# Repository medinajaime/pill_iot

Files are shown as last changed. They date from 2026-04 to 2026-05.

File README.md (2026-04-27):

# Smart Pill Dispenser (智慧藥盒)

An IoT smart medication management system designed for Taiwan's elderly population. The companion app combines prescription recognition with automatic dispensing to help users manage their medications safely and effectively.

## Features

- **Prescription Scanning** - Scan Taiwan NHI prescription QR codes to automatically import medications
- **Medication Scheduling** - Daily and weekly medication schedule views
- **Adherence Tracking** - Track medication compliance with history and statistics
- **IoT Dispenser Integration** - Connect to smart pill dispenser via Bluetooth/WiFi
- **Caregiver Dashboard** - Allow family members to monitor medication adherence remotely
- **Multi-language Support** - English and Traditional Chinese (繁體中文)
- **Elderly-Friendly UI** - Large fonts, high contrast options, voice prompts

## Screenshots

*Coming soon*

## Getting Started

### Prerequisites

- Flutter SDK 3.16.0 or higher
- Android Studio / VS Code
- Java JDK 17
- Android SDK (API 23+)

### Installation

1. **Clone the repository**
   ```bash
   git clone git@github.com:medinajaime/pill_iot_dispenser.git
   cd pill_iot_dispenser
   ```

2. **Install dependencies**
   ```bash
   flutter pub get
   ```

3. **Generate code** (for freezed/json_serializable)
   ```bash
   dart run build_runner build --delete-conflicting-outputs
   ```

4. **Run the app**
   ```bash
   flutter run
   ```

### Firebase Setup (Required for Production)

1. Create a Firebase project at [console.firebase.google.com](https://console.firebase.google.com)
2. Enable Authentication, Firestore, Cloud Messaging, and Storage
3. Download `google-services.json` and place in `android/app/`
4. Run `flutterfire configure` to generate Firebase options
5. Uncomment Firebase initialization in `lib/main.dart`

## Project Structure

```
lib/
├── main.dart                 # App entry point
├── app.dart                  # MaterialApp configuration
├── core/
│   ├── localization/         # i18n (English & Chinese)
│   ├── router/               # GoRouter navigation
│   ├── theme/                # App theme & styling
│   └── utils/                # Utilities (QR parser, etc.)
├── data/
│   └── models/               # Data models (freezed)
├── presentation/
│   ├── providers/            # Riverpod state management
│   ├── screens/              # App screens
│   └── widgets/              # Reusable widgets
└── services/                 # Business logic & API services
```

## Tech Stack

| Category | Technology |
|---|---|
| Framework | Flutter 3.16+ |
| State Management | Riverpod |
| Navigation | GoRouter |
| Local Storage | Hive, SharedPreferences |
| Backend | Firebase (Auth, Firestore, Messaging, Storage) |
| Bluetooth | flutter_blue_plus |
| QR Scanning | mobile_scanner |
| Notifications | flutter_local_notifications |

## Building

### Debug APK
```bash
flutter build apk --debug
```

### Release APK
```bash
flutter build apk --release
```

### App Bundle (Play Store)
```bash
flutter build appbundle --release
```

Output location: `build/app/outputs/flutter-apk/`

## Configuration

### Environment Variables

Create `android/app/google-services.json` with your Firebase configuration (not committed to git).

### Changing App ID

Update the application ID in `android/app/build.gradle.kts`:
```kotlin
applicationId = "com.yourcompany.smartpilldispenser"
```

## Localization

The app supports:
- **English** (en-US)
- **Traditional Chinese** (zh-TW)

Language can be switched in Settings > Display Settings > Language.

To add translations, edit `lib/core/localization/app_localizations.dart`.

## Development

### Demo Mode

The app includes a demo mode with mock data for testing without a real dispenser. Toggle in Settings > Developer Options > Demo Mode.

### Running Tests
```bash
flutter test
```

### Code Generation
```bash
dart run build_runner watch  # Watch mode
dart run build_runner build --delete-conflicting-outputs  # One-time build
```

## Roadmap

See [TASKS.md](TASKS.md) for detailed integration tasks and remaining work.

### Priority Features
- [ ] Firebase backend integration
- [ ] Push notifications for medication reminders
- [ ] Real Bluetooth device pairing
- [ ] LINE messaging integration
- [ ] Voice prompts (Mandarin/Hokkien)

## Contributing

1. Fork the repository
2. Create a feature branch (`git checkout -b feature/amazing-feature`)
3. Commit your changes (`git commit -m 'Add amazing feature'`)
4. Push to the branch (`git push origin feature/amazing-feature`)
5. Open a Pull Request

## Authors

- **Marcus Canul**
- **Jaime Medina**

## License

This project is proprietary. All rights reserved.

## Acknowledgments

- Designed for Taiwan's National Health Insurance (NHI) prescription system
- Built with accessibility in mind for elderly users
- IoT hardware integration for automated pill dispensing

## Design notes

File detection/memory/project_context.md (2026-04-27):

---
name: Hero Smart Pill Dispenser — Project Context
description: Full context of the pill detection system being built for a Taiwan-focused IoT smart pill dispenser
type: project
---

Smart IoT pill dispenser for Taiwan's elderly population. School project (Jaime Medina + Marcus Canul).

**Core flow:**
1. User scans paper prescription or NHI QR code in Flutter app
2. App OCRs/parses prescription → sends medication list (with NHI codes, color, shape) to Pi over BLE
3. User physically loads pills one medication type at a time (no app guidance required)
4. Pi camera images each pill in optical chamber → identifies which prescription medication it is
5. Routes pill to correct carousel slot
6. Pills dispensed automatically on schedule, or on demand

**Why:** Taiwan becoming super-aged society (20%+ over 65 by 2025). Reduces medication errors and caregiver burden.

**Detection approach:**
- Open identification against ≤10 prescription medications (not global database)
- MobileNetV2 fine-tuned on ePillID public dataset → TFLite INT8 for Pi 4
- Metric learning: embedding-based matching (cosine similarity), no retraining when new pills added
- Auto-registration: first 3-5 pills of each type captured automatically; NHI color/shape used as prior
- Three outcomes: MATCH (auto-route) / UNSURE (hold, notify app) / NO_MATCH (hold, alert)
- Confirmation button on app/dispenser for UNSURE cases — shows pill photo to user

**Three confidence tiers:**
- MATCH: confidence ≥ high_threshold → route silently
- UNSURE: between thresholds → hold pill, send alert + image to app, wait for YES/NO
- NO_MATCH: confidence < low_threshold → hold, alert (wrong pill)

**Hardware (Pi 4):** Pi Camera v2 at 45° tilt, NeoPixel LED ring, NEMA17 carousel, SG90 trapdoor servo, HX711 load cell, TCST2103 home sensor

**Files to build:**
- capture.py — Pi Camera v2 + NeoPixel (done)
- preprocess.py — perspective correction + segmentation + feature extraction (done, needs feature update)
- database.py — prescription-driven profile storage
- model.py — TFLite wrapper + cosine similarity matching
- train.py — fine-tune MobileNetV2 on ePillID, export TFLite INT8
- pipeline.py — full state machine orchestration
- ble_server.py — BLE peripheral (bless) + HTTP fallback (Flask)

**Why:** Taiwan becoming super-aged society (20%+ over 65 by 2025). Reduces medication errors and caregiver burden.

**Phase 2:** Add Taiwan NHI-specific pill images via few-shot fine-tuning.

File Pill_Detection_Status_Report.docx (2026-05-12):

Hero Smart Pill Dispenser

Pill Detection System — Status Report

Author: Jaime Medina Date: 29 April 2026

# 1. System Overview

The Hero Smart Pill Dispenser combines three components that work together as a complete care pipeline: (a) a Flask “Raspberry Pi simulator” server hosting a real ML pill-detection pipeline; (b) a Flutter mobile app for end-users and caregivers; and (c) a Three.js 3D viewer showing the physical Fusion 360 model with live mechanical animation tied to real device events.

Pill detection — identifying which medication a user has just placed in the chamber — is the project’s main selling point and is the focus of this report.

# 2. Detection ML Pipeline (the core)

The detection system uses a hybrid neural + classical approach to identify pills against the user’s active prescription.

Component | Implementation | File
Embedding model | MobileNetV2 ONNX, 1280-dim L2-normalised embeddings, ImageNet normalisation, 224×224 input. ONNX Runtime selects TensorRT → CUDA → CPU automatically. | detection/model.py (EmbeddingModel)
Image preprocessing | Perspective correction → Otsu segmentation → bounding-box crop → 224×224 resize. Outputs the tensor plus a 68-dim classical feature vector (HSV histograms + shape descriptors). | detection/preprocess.py
Matcher | Hybrid score: 65% neural cosine similarity + 35% classical similarity (chi-squared HSV histograms + L2 shape distance). Thresholds: MATCH ≥ 0.10, UNSURE ≥ 0.04, else NO_MATCH. | detection/model.py (PillMatcher)
Profile database | NHI-code-keyed storage: per-pill embedding.npy + classical.npy + reference images. JSON index for metadata. | detection/database.py (PillDatabase)
Auto-registration | First 3 captured pills of each medication automatically build the reference profile (mean embedding, mean classical features). From pill 4 onwards matching uses the locked profile. | detection/demo_server.py::_infer_pill_image
Cold-start fallback | When no profiles or accumulators exist yet, the system falls back to NHI shape/colour priors from the prescription so detection still produces a reasonable answer on the very first pill. | detection/demo_server.py::_nhi_prior_match

Why this matters: the user does not need to pre-photograph reference pills before the demo. The system learns each medication’s profile from the first 3 pills loaded, then matches all subsequent pills against the locked embedding with high confidence.

# 3. Server Endpoints (the “Raspberry Pi” simulator)

Running on the laptop as a stand-in for the real Pi, with persistent state across reboots.

Endpoint | Purpose
POST /detect | Real ONNX inference. Accepts multipart image + slot. Runs preprocess → embed → match → returns {result, confidence, detected_nhi, detected_name, top_candidates, auto_registered}. Saves the capture for viewer display.
GET /recent_capture.jpg | Serves the last uploaded pill image to the 3D viewer’s camera mini-window.
POST /prescription | Loads the user’s medication list into the matcher’s NHI prior database.
POST /load_pill, POST /dispense | Mechanical sequence triggers (drive 3D animation in the viewer).
GET /device_info, POST /reset, POST /app/connect | Pi-like device identity (serial, firmware, uptime), factory reset, app pairing handshake.
GET /events/recent | Polling endpoint streaming detection + mechanical events to the viewer and the app.

Device state is persisted to pi_state.json so the server behaves like a real device that remembers its loaded slots and paired user across power cycles.

# 4. Flutter App Integration

The mobile app drives the entire workflow.

Capability | Status | Notes
QR-code prescription scan | Working | mobile_scanner parses Taiwan NHI QR codes; extracts NHI codes, hospital, doctor, medication list with dosage and frequency.
OCR prescription scan | Working | google_mlkit_text_recognition for Chinese; falls back to manual entry if OCR confidence is low.
Manual entry | Working | Standard form.
Auto-send prescription to dispenser | Working | After save, app POSTs to /prescription if HTTP mode is active.
Loading Wizard | Working | Step-by-step guided loading of every medication; pill counter (已裝載 N / Quantity) per medication.
Pill detection in wizard | Server-side ready, app camera UI being added | Plan: replace blind “tap Confirm” with phone-camera capture → multipart upload to /detect → branch on MATCH/UNSURE/NO_MATCH.
Schedule + dose times | Working | Builds daily schedule from prescription frequency (QD/BID/TID/QID/HS) with default dose times.
Home dispense flow | Working | “立即出藥” button when the next dose is overdue or within 30 min; “Did you take it?” confirmation marks the dose as taken in the dose log.
Live dispenser status banner | Working | Top-of-home pill chip: 藥盒已連線 / 連線中 / 無法連線 / 藥盒離線 / 模擬模式.
3D demo trigger from app | Working | Dispenser status screen launches the full mechanical animation in the 3D viewer.
Adherence history & tracking | Working | Hive local cache + Firestore sync.
Multi-mode connection | Working | Mock (no hardware), HTTP (laptop server, current demo), BLE (real Pi) — all switchable in setup screen.

The Riverpod state pattern keeps prescription / schedule / dispenser providers reactive, so the home screen, wizard, and viewer all update when any layer changes.

# 5. LINE Messaging Integration

Taiwan-specific user-facing notification channel via LINE Notify.

Capability | Status | File
LINE Notify token storage | Working | lib/services/line_service.dart
Dose reminder push | Working | Sends “請服用 [medication]” when a dose fires.
Adherence reports to caregivers | Working | Daily summary push to a paired caregiver’s LINE group.
Caregiver dashboard | Working | Caregivers see real-time adherence status and missed doses.
LINE settings UI | Working | Setup screen in app for token + group binding.

# 6. Supporting Systems

- 3D digital twin viewer (detection/viewer.html): Three.js render of the actual Fusion 360 GLB. Real component pivots animated by server events. Cutaway transparency reveals internal pill flow during loading and dispensing. “Last Detection” panel + camera mini-window for showing detection results is the next planned addition.
- Voice notifications: TTS-based dose reminders for elderly users with low literacy.
- Multi-language: Traditional Chinese (primary) + English UI strings throughout.
- Persistent device pairing: First app-connect pairs the device to a user ID; survives Pi reboots via pi_state.json.

# 7. What’s Working End-to-End Today

1. Open Flutter app → pair to laptop server (acts as the Pi).
2. Scan a Taiwan NHI prescription QR code → app extracts medications + NHI codes → auto-pushes to server.
3. Server sends prescription into PillDatabase for NHI-prior matching.
4. Open Loading Wizard → walk through each medication.
5. POST /detect with a real pill photo runs the full ONNX pipeline, returns real confidence and NHI code (verified end-to-end with the ePillID test dataset).
6. Auto-registration locks the medication’s reference profile after 3 successful detections.
7. Server fires real mechanical events → 3D viewer animates the pill flow with cutaway transparency.
8. Dispense flow: home screen “立即出藥” → server runs sequence → “您是否已服用此藥?” dialog marks the dose as taken.
9. LINE notifies caregivers of missed doses.
10. State persists across server reboots in pi_state.json + auto-registered profiles in data/profiles/.

# 8. Active Work

- Flutter camera capture step in the Loading Wizard (replacing the current blind-confirm flow with real image_picker → /detect).
- DetectionResult Freezed model in the app.
- Viewer detection panel + camera mini-window showing the real uploaded image and detection result with LED / pill colour driven by MATCH / UNSURE / NO_MATCH.

Bottom line: the detection backend is the demonstrably real part — reviewers can run curl -F slot=1 -F image=@pill.jpg http://localhost:5000/detect right now and receive a real ONNX-inference result with measurable confidence, against the user’s active prescription.

Hero Smart Pill Dispenser · Detection Status Report

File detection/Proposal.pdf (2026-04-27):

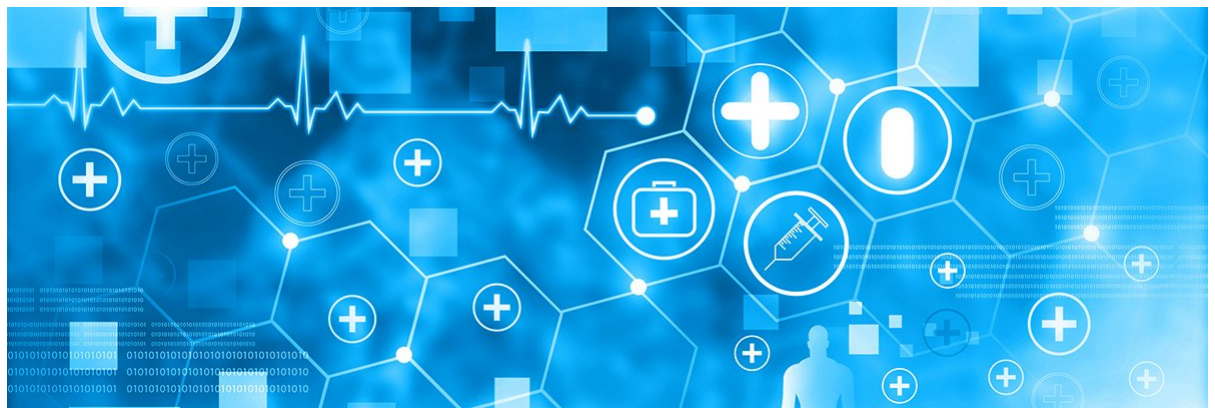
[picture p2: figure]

# 智慧藥盒

## 結合處方辨識與自動分配的 IoT 智慧藥物管理系統

## Smart IoT Pill Dispenser

### Prescription-Aware Automated Medication Management System

## Project Proposal

Team Members: 411221333 Marcus Canul 411221327 Jaime Medina
Advisor:
Date: 17 September 2025

# Project Proposal

## 智慧藥盒：處方辨識與自動分配系統

(Smart Pill Dispenser: Prescription-Aware Automated Medication System for Taiwan’s Aging Society)

### 1. Introduction & Problem Statement

By 2025, Taiwan becomes a super-aged society (20%+ population over 65). Elderly

patients often juggle multiple prescriptions, which creates risks of:

- Medication errors: wrong pill, wrong time, overdose, or missed doses.
- Caregiver burden: family members must prepare daily pillboxes and remind elders.
- Health risks: poor adherence leads to preventable hospitalizations.

Current gap: Existing dispensers only remind users to take pills but cannot verify pill type, automatically sort pills, or adapt to Taiwan’s NHI prescription system.

### 2. Project Objectives

We propose to design an IoT-enabled smart pill dispenser with these goals:

### 1. Prescription-Aware Automation

- Import doctor’s prescription via NHI QR code / app screenshot or scan/upload

prescription paper.

- Parse medication names, dosages, and schedules automatically.

### 2. Pill Recognition & Sorting (Package-Based Intake)

- Users load one entire package of pills at a time into the container.
- System uses camera + ML to recognize each pill (shape, color, imprint).
- Pills are then sorted into correct compartments according to prescription.

### 3. Automated Dispensing

- At scheduled times, the device releases the correct set of pills into a cup.
- Provides voice, vibration, and LINE alerts as reminders.

### 4. Adherence Monitoring

- Detects pill retrieval (via load cell/sensor).
- Logs medication history and alerts caregivers for missed doses.

### 5. Lightweight Companion App

To complement the dispenser, we propose a simple companion app for caregivers and family members. The app remains lightweight and focused on usability rather than technical complexity. Core features include:

- Prescription Import: Scan/upload NHI QR code or photo of doctor’s prescription.
- Schedule Overview: View daily/weekly medication schedule in Traditional Chi-

nese.

- Reminders & Alerts: Receive notifications of taken/missed doses (mirrored to

LINE).

- Adherence Tracking: Access history of medication intake, with missed-dose logs.
- Caregiver Integration: Allow family members to monitor and receive alerts re-

motely.

- Language Support: Traditional Chinese interface with Mandarin/Hokkien voice

prompt options.

- Simple Setup: Pair dispenser, adjust time settings, and manage basic configura-

tions.

The app is intentionally minimal: elderly users interact primarily with the device and LINE notifications, while caregivers use the app to set up, monitor, and adjust prescriptions when needed.

### 3. Novelty & Contribution

- End-to-End Integration: Combines prescription parsing, pill recognition, sorting,

and dispensing.

- Taiwan Localization:

– Traditional Chinese interface, Mandarin/Hokkien voice prompts.

– LINE notification system.

– Support for NHI prescription QR codes.

- Affordable Modular Design: Core dispenser with optional caregiver app.
- Social Impact: Supports Long-Term Care 2.0 and Smart Healthcare initiatives.

### 4. Technical Approach

Hardware

- Microcontroller: ESP32 / Raspberry Pi
- Sensors: PiCam (pill recognition), load cell (dispense confirmation)
- Motors: Stepper/servo for sorting & dispensing
- Connectivity: WiFi/GSM for LINE integration
- Output: Speaker, LED, vibration motor

Software

- Prescription parser: QR/barcode → structured schedule & pill list
- Computer Vision: TensorFlow Lite model for pill recognition
- IoT Platform: MQTT or Firebase + LINE API integration
- Scheduler: Embedded logic for dispensing + adherence monitoring

### 5. Development Plan & Timeline (Two Semesters)

Semester 1 (Sep 2025 – Jan 2026)

- Prescription parsing (NHI QR code, app input)
- Hardware setup + basic pill container (package intake)
- Pill recognition prototype with ML model
- Sorting mechanism: package → compartments
- Mid-term demo: package intake → pill recognition → sorting

Semester 2 (Feb 2026 – Jun 2026)

- Automated dispensing module (compartment → cup)
- Reminders (voice, vibration, LINE integration)
- Adherence monitoring (sensors + caregiver alerts)
- Usability testing with elderly/caregiver groups
- Final refinement, UI/UX polish, bilingual prompts
- Final demo + presentation

### 6. Expected Outcomes

- A working prototype:

– Intake: loads one pill package at a time.

– Sorting: places pills into correct compartments.

– Dispensing: releases pills on schedule.

– Alerts: LINE, vibration, and voice.

- Demonstration with 3–5 pill types and sample Taiwan prescriptions.
- Evaluation of recognition accuracy, user feedback, and adherence improvement.

### 7. Impact

- Academic: Combines IoT, ML, and healthcare technologies.
- Social: Reduces caregiver stress and helps elders maintain independence.
- Practical: Ready for real-world testing in clinics, pharmacies, and care centers.

### 8. Conclusion

This project creates a next-generation smart pill dispenser for Taiwan’s aging society. By integrating AI-driven pill recognition, NHI prescription parsing, and IoT-enabled reminders, it addresses a critical healthcare gap and offers a localized, affordable solution for elderly medication management.

## Gantt-Style Timeline (Sep 2025 – Jun 2026)

### Semester 1 (Fall 2025)

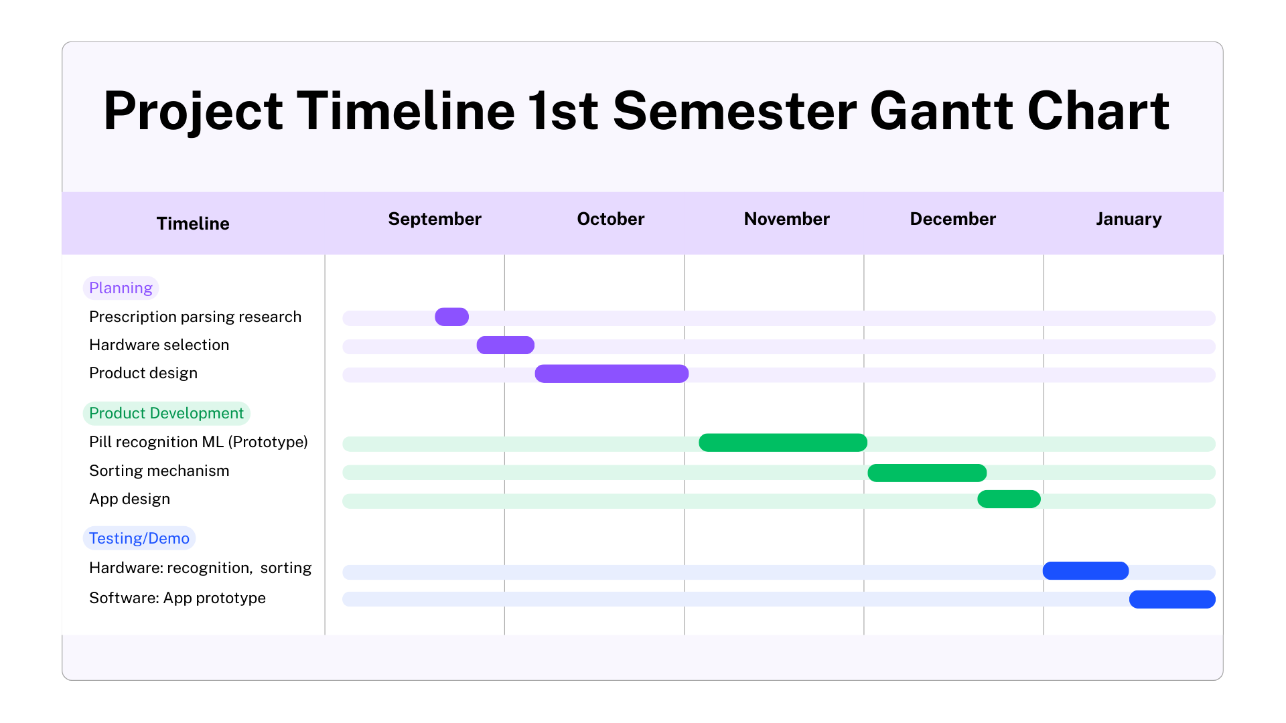
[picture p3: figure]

Month-by-month plan

- Sep — Prescription parsing, hardware selection
- Oct — Basic pill container & package intake design
- Nov — Pill recognition ML (prototype dataset)
- Dec — Sorting mechanism (package → compartments), app wireframes & design
- Jan — Mid-term demo (intake + recognition + sorting), app prototype (prescrip-

tion import + schedule view)

## Gantt-Style Timeline (Sep 2025 – Jun 2026)

### Semester 2 (Spring 2026)

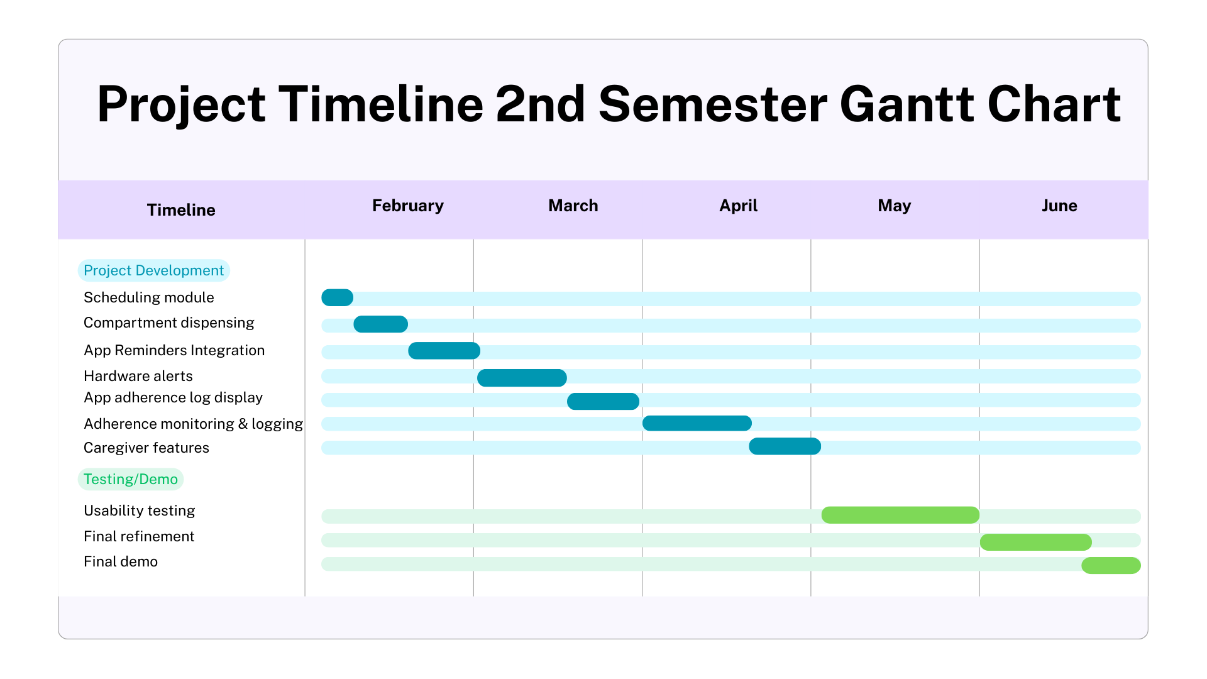
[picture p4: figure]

Month-by-month plan

- Feb — Scheduling module + compartment dispensing; app reminders integration
- Mar — LINE reminders + hardware alerts; app adherence log display
- Apr — Adherence monitoring + logging; caregiver features (multi-user alerts)
- May — Usability testing (elderly/caregivers) for dispenser & app
- Jun — Final refinement + bilingual UI + final demo (device + companion app)

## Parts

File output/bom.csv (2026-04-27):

Part | Description | Qty | W_in | D_in | H_in | W_mm | D_mm | H_mm | Vol_in3 | Vol_cm3 | Material | Process | Color | Note
enclosure | D-profile main enclosure shell (9"W x 9"D x 15"H) | 1 | 11.25 | 9.0 | 15.0 | 285.75 | 228.6 | 381.0 | 1518.7501 | 24887.758 | PETG | FDM — 3-section split | Light blue-gray
button | Centre multi-directional button cap | 1 | 1.75 | 1.75 | 0.15 | 44.45 | 44.45 | 3.81 | 0.4594 | 7.528 | PETG | FDM | Black
pill_cup | Dispensing cup with solid floor and front grab tab | 1 | 2.5 | 2.68 | 1.5 | 63.5 | 68.07 | 38.1 | 10.05 | 164.689 | PETG | FDM | White
drop_cone | Anti-bounce funnel between spout and pill cup | 1 | 2.1 | 2.1 | 2.15 | 53.34 | 53.34 | 54.61 | 9.4815 | 155.373 | TPU 95A | FDM -- flexible nozzle | Translucent white
hatch_final | Top loading hatch lid with hinge knuckles + snap latch | 1 | 11.25 | 9.36 | 0.27 | 285.75 | 237.74 | 6.86 | 28.431 | 465.899 | PETG | FDM | Light blue-gray
usbc_port | USB-C port bezel insert | 1 | 0.41 | 0.1 | 0.18 | 10.41 | 2.54 | 4.57 | 0.0074 | 0.121 | PETG | FDM | Light steel
speaker_grille | Speaker grille — 12-hole ring pattern | 1 | 1.5 | 0.05 | 1.5 | 38.1 | 1.27 | 38.1 | 0.1125 | 1.844 | PETG | FDM | Dark gray
display_panel | Touchscreen display placeholder panel | 1 | 3.0 | 0.08 | 3.5 | 76.2 | 2.03 | 88.9 | 0.84 | 13.765 | Off-the-shelf | 3.5" TFT LCD module | Black
led_ring | Front-face status LED ring (outer R=1.2") | 1 | 2.4 | 0.05 | 2.4 | 60.96 | 1.27 | 60.96 | 0.288 | 4.719 | Off-the-shelf | NeoPixel ring | N/A
cartridge | Pill storage cartridge (×10 installed) | 10 | 2.783 | 2.047 | 3.9 | 70.69 | 51.99 | 99.06 | 22.2114 | 363.978 | PETG | FDM | Translucent amber
carousel_base | Carousel base plate (stationary, 0.10" thick) | 1 | 7.0 | 7.0 | 0.1 | 177.8 | 177.8 | 2.54 | 4.9 | 80.296 | PETG | FDM | Dark steel
hub_lock | Central hub lock ring — couples D-shaft to carousel | 1 | 1.5 | 1.5 | 3.9 | 38.1 | 38.1 | 99.06 | 8.775 | 143.796 | PETG | FDM | Gray
motor_assembly | NEMA 17 stepper motor + D-shaft placeholder | 1 | 1.7 | 1.7 | 5.5 | 43.18 | 43.18 | 139.7 | 15.895 | 260.471 | Off-the-shelf | NEMA 17 42x42x47mm | Black
motor_mount | NEMA 17 motor mount plate (3"x3"x0.10") | 1 | 3.0 | 3.0 | 0.1 | 76.2 | 76.2 | 2.54 | 0.9 | 14.748 | PETG | FDM | Dark steel
dispense_gate | Upper inlet gate for one-tablet metering chamber | 1 | 1.48 | 0.92 | 0.035 | 37.59 | 23.37 | 0.89 | 0.0477 | 0.781 | PETG | FDM | Orange
dispense_gate_servo_mount | SG90 mount for upper inlet gate | 1 | 1.3 | 0.7 | 0.83 | 33.02 | 17.78 | 21.08 | 0.7553 | 12.377 | PETG | FDM | Black
dispense_release_gate | Lower release gate below one-tablet metering chamber | 1 | 1.42 | 0.8 | 0.035 | 36.07 | 20.32 | 0.89 | 0.0398 | 0.652 | PETG | FDM | Amber
dispense_release_gate_servo_mount | SG90 mount for lower release gate | 1 | 1.3 | 0.7 | 0.83 | 33.02 | 17.78 | 21.08 | 0.7553 | 12.377 | PETG | FDM | Black
dispense_sweep_pusher | Low front-entry TPU last-pill pusher | 1 | 0.58 | 0.795 | 0.115 | 14.73 | 20.19 | 2.92 | 0.053 | 0.869 | TPU 95A | FDM -- flexible nozzle | Blue
dispense_sweep_containment_band | Stationary OD shield backing all cartridge sweep slots | 1 | 7.24 | 7.24 | 0.42 | 183.9 | 183.9 | 10.67 | 22.0154 | 360.766 | PETG | FDM | Light gray
dispense_sweep_port_seal | Flexible TPU wiper sealing the single pusher service window | 1 | 0.99 | 0.055 | 0.42 | 25.15 | 1.4 | 10.67 | 0.0229 | 0.375 | TPU 95A | FDM -- flexible nozzle | Black
dispense_sweep_rail | Low front linear guide rail for sweep pusher | 1 | 1.35 | 0.75 | 0.26 | 34.29 | 19.05 | 6.6 | 0.2632 | 4.314 | PETG | FDM | Dark gray
dispense_sweep_servo_mount | Low SG90/rack mount for front-entry pusher | 1 | 1.25 | 0.62 | 0.71 | 31.75 | 15.75 | 18.03 | 0.5502 | 9.017 | PETG | FDM | Black
pill_guide | Guide tube / loading chimney (R=3.5", H=2.1") | 1 | 7.0 | 7.0 | 2.1 | 177.8 | 177.8 | 53.34 | 102.9 | 1686.222 | PETG | FDM — translucent | Translucent green
pill_guide_ring | Top seal ring — solid ceiling with single loading port | 1 | 6.86 | 6.86 | 0.05 | 174.24 | 174.24 | 1.27 | 2.353 | 38.558 | PETG | FDM | Light gray
pill_chute | One-tablet metering chamber / sealed dispense chute | 1 | 0.9 | 0.9 | 0.285 | 22.86 | 22.86 | 7.24 | 0.2309 | 3.783 | PETG | FDM | Light gray
load_cell | Circular load-cell tray under removable pill cup | 1 | 2.6 | 2.6 | 0.1 | 66.04 | 66.04 | 2.54 | 0.676 | 11.078 | Off-the-shelf | HX711 + 1kg load cell | Gold
loading_tube | Vertical loading tube (inner R=1.80", H=3.9") | 1 | 3.8 | 3.8 | 3.9 | 96.52 | 96.52 | 99.06 | 56.316 | 922.85 | PETG | FDM — translucent | Translucent green
routing_chute | Static routing chute — lofted funnel, trapdoor to slot | 1 | 2.879 | 4.663 | 4.0 | 73.13 | 118.44 | 101.6 | 53.6977 | 879.944 | PETG | FDM | Translucent amber
trapdoor_left | Trapdoor left leaf (semicircle, X<=0) | 1 | 1.4 | 2.8 | 0.04 | 35.56 | 71.12 | 1.02 | 0.1568 | 2.569 | Matte White PETG | FDM or laser-cut | Matte White
trapdoor_right | Trapdoor right leaf (semicircle, X>=0) | 1 | 1.4 | 2.8 | 0.04 | 35.56 | 71.12 | 1.02 | 0.1568 | 2.569 | Matte White PETG | FDM or laser-cut | Matte White
hinge_pin | Trapdoor hinge pin (Y-axis, R=0.04", L=3.00") | 1 | 0.08 | 3.0 | 0.08 | 2.03 | 76.2 | 2.03 | 0.0192 | 0.315 | Steel | Off-the-shelf rod | Silver
servo_mount | SG90 servo body + ears + drive arm assembly | 1 | 1.4 | 1.07 | 0.63 | 35.56 | 27.18 | 16.0 | 0.9437 | 15.465 | Off-the-shelf | SG90 micro servo | Dark gray
chamber_shell | Optical detection chamber cylinder (R=1.50", H=2.00") | 1 | 3.0 | 3.0 | 2.0 | 76.2 | 76.2 | 50.8 | 18.0 | 294.966 | Clear PETG | FDM — translucent | Translucent green
camera_mount | Camera mount bridge — 45-deg downward in annular gap | 1 | 0.403 | 0.4 | 0.403 | 10.24 | 10.16 | 10.24 | 0.0648 | 1.062 | PETG | FDM | Black
led_ring_oc | Optical chamber LED ring (torus, R=1.30", at ceiling) | 1 | 0.1 | 0.0 | 0.1 | 2.54 | 0.0 | 2.54 | 0.0 | 0.0 | Off-the-shelf | LED ring / bare LEDs | Warm yellow
chamber_ceiling | Frosted PETG ceiling plate — LED mount + light baffle + diffuser | 1 | 2.8 | 2.8 | 0.05 | 71.12 | 71.12 | 1.27 | 0.392 | 6.424 | Frosted PETG | FDM — translucent | Translucent white
vertical_pcb | Raspberry Pi 4 PCB — vertical back-wall mount | 1 | 3.35 | 0.363 | 2.2 | 85.09 | 9.22 | 55.88 | 2.6753 | 43.84 | Off-the-shelf | Raspberry Pi 4 Model B | Green PCB
vib_motor | Vibration motor (agitation assist, R=0.30") | 1 | 0.6 | 0.6 | 0.5 | 15.24 | 15.24 | 12.7 | 0.18 | 2.95 | Off-the-shelf | ERM coin vibration motor | Gray
camera | Camera module — main imaging sensor | 1 | 0.98 | 0.94 | 0.45 | 24.89 | 23.88 | 11.43 | 0.4145 | 6.793 | Off-the-shelf | Pi Camera v2 / OV5647 | Black
rear_shaft | Rear D-shaft extension below motor body (R=0.20", L=0.50") | 1 | 0.4 | 0.35 | 0.5 | 10.16 | 8.89 | 12.7 | 0.07 | 1.147 | Steel | Off-the-shelf rod | Silver
index_disk | Slotted encoder disk — 1 notch, R=0.60", T=0.05" | 1 | 1.196 | 1.2 | 0.05 | 30.38 | 30.48 | 1.27 | 0.0718 | 1.176 | PETG | FDM | Black
sensor_mount | TCST2103 fork sensor L-bracket mount | 1 | 0.46 | 0.47 | 0.45 | 11.68 | 11.94 | 11.43 | 0.0973 | 1.594 | PETG | FDM | Black
optical_interrupter | TCST2103 fork optical interrupter (home pulse sensor) | 1 | ? | ? | ? | ? | ? | ? | ? | ? | Off-the-shelf | TCST2103 | Black | STEP missing

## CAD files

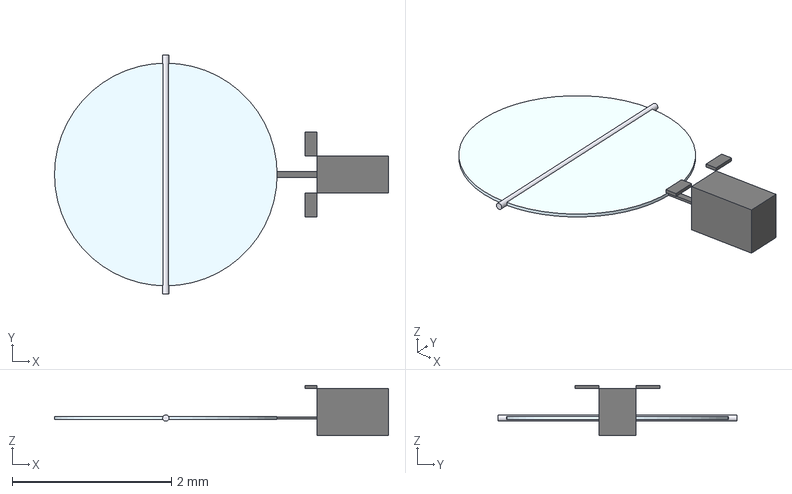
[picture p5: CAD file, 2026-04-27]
output/trapdoor_assembly.step
4.20 x 3.00 x 0.63 mm
trapdoor_left
trapdoor_right
hinge_pin
servo_mount

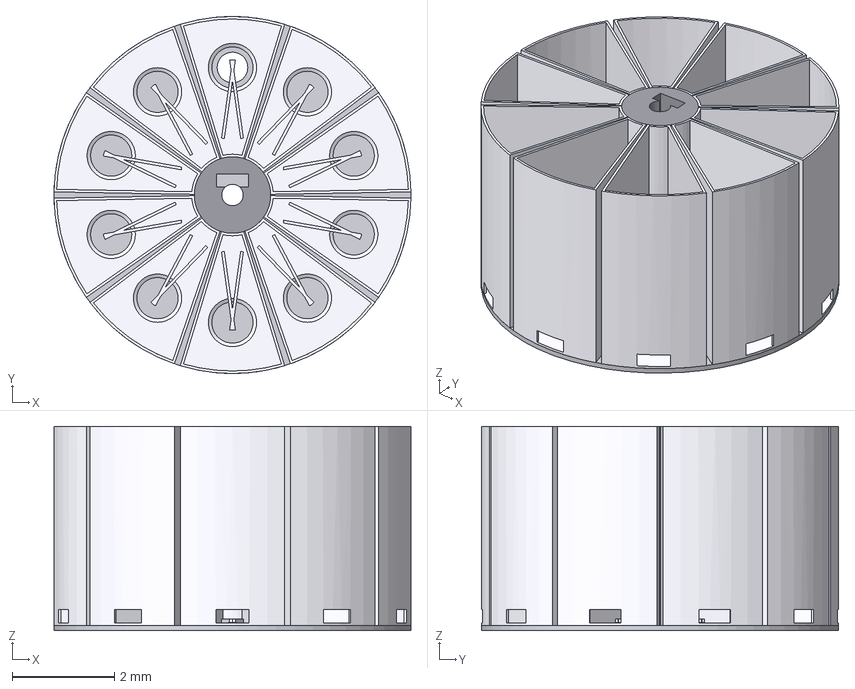
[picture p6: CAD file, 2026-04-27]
output/carousel_assembly.step
7.00 x 7.00 x 4.00 mm
cartridge_00
cartridge_01
cartridge_02
cartridge_03
cartridge_04
cartridge_05
cartridge_06
cartridge_07
cartridge_08
cartridge_09
hub_lock
base

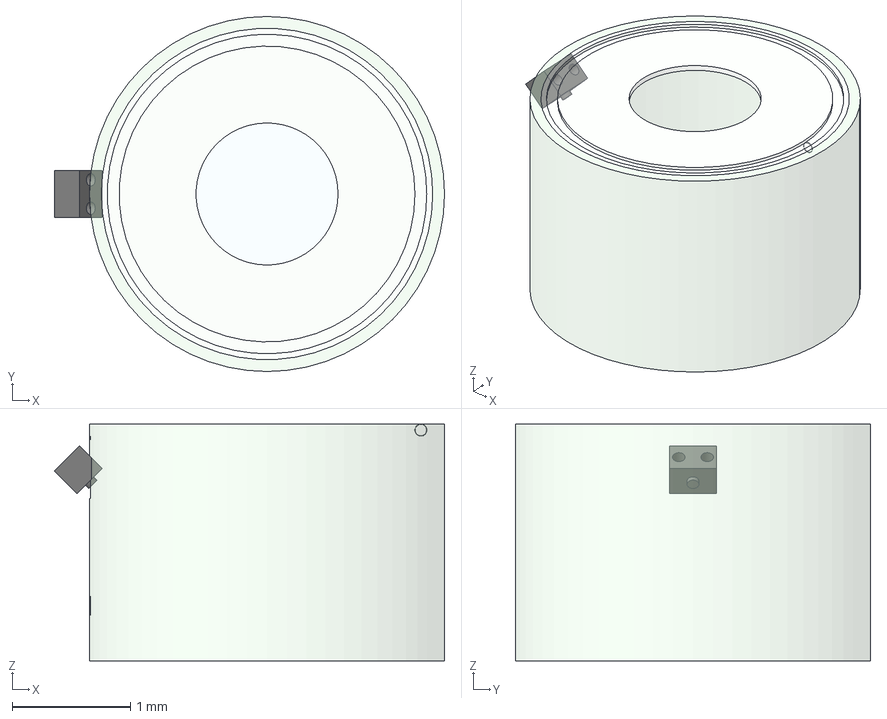
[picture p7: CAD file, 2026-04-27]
output/optical_chamber_assembly.step
3.30 x 3.00 x 2.00 mm
chamber_shell
staging_floor
camera_mount
led_ring_oc
chamber_ceiling

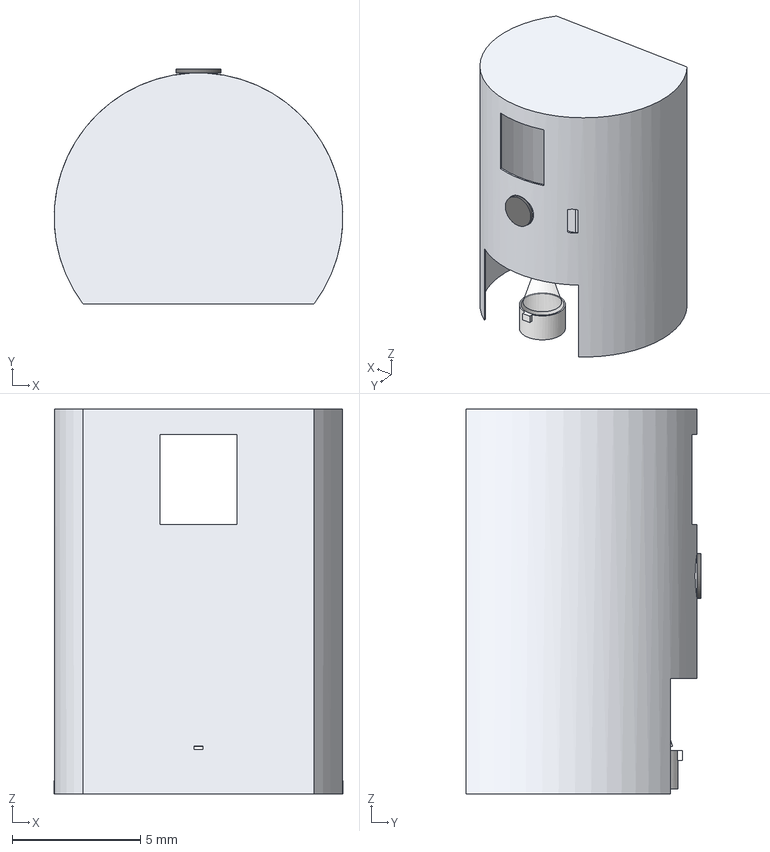
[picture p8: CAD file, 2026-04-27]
output/hero_dispenser_assembly.step
11.2 x 9.15 x 15.0 mm
enclosure
button
pill_cup
drop_cone

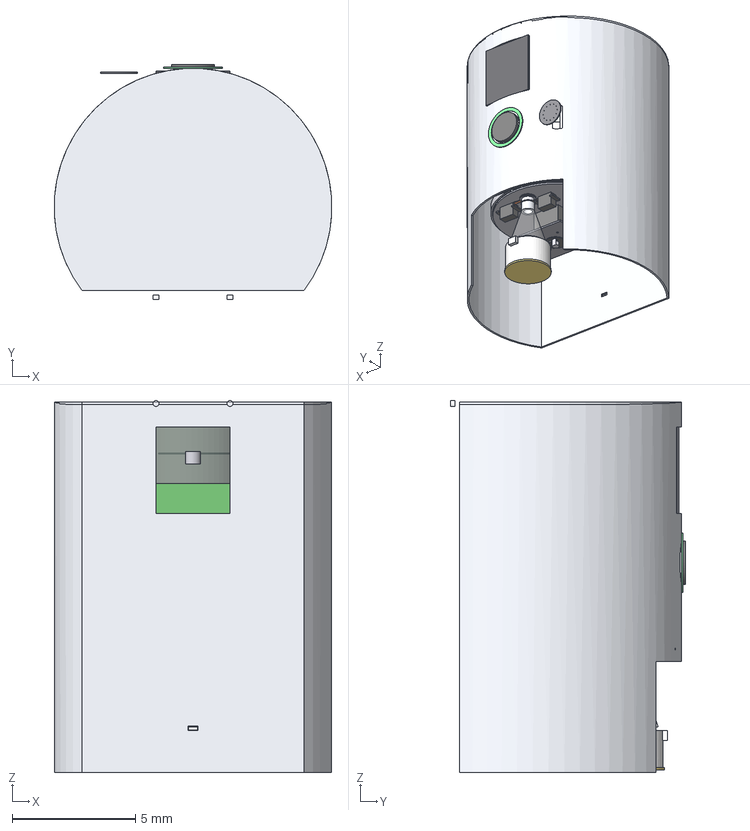
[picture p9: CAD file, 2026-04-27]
output/hero_full_assembly.step
11.2 x 9.51 x 15.1 mm
enclosure
button
pill_cup
drop_cone
cartridge_00
cartridge_01
cartridge_02
cartridge_03
cartridge_04
cartridge_05
cartridge_06
cartridge_07
cartridge_08
cartridge_09
hub_lock
base
motor_assembly
dispense_gate
dispense_gate_servo_mount
dispense_release_gate
dispense_release_gate_servo_mount
dispense_sweep_pusher
dispense_sweep_containment_band
dispense_sweep_port_seal
dispense_sweep_rail
dispense_sweep_servo_mount
pill_guide
load_cell
vib_motor
pill_chute
motor_mount
display_panel
led_ring
hatch_final
usbc_port
speaker_grille
loading_tube
pill_guide_ring
vertical_pcb
chamber_shell
camera_mount
led_ring_oc
chamber_ceiling
trapdoor_left
trapdoor_right
hinge_pin
servo_mount
routing_chute
rear_shaft
index_disk
sensor_mount

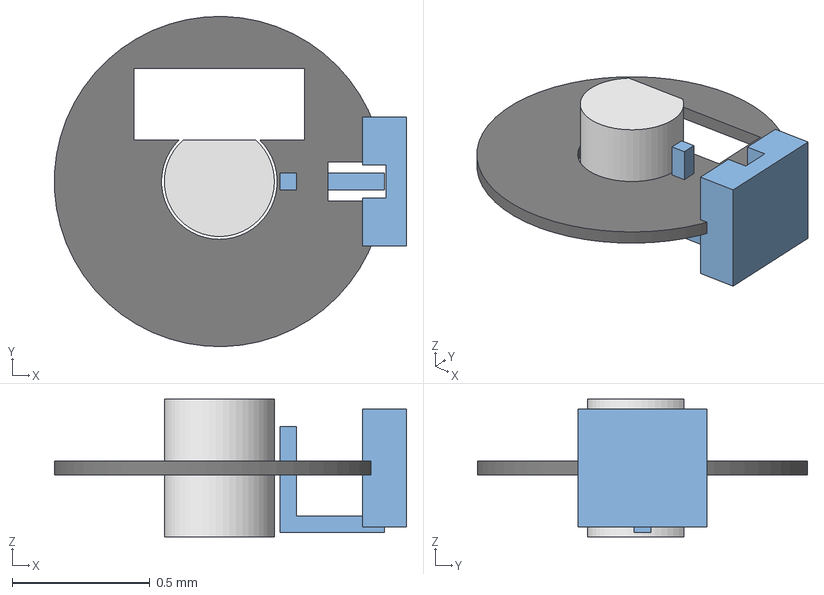
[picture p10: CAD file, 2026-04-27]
output/index_wheel_assembly.step
1.28 x 1.20 x 0.5 mm
rear_shaft
index_disk
sensor_mount

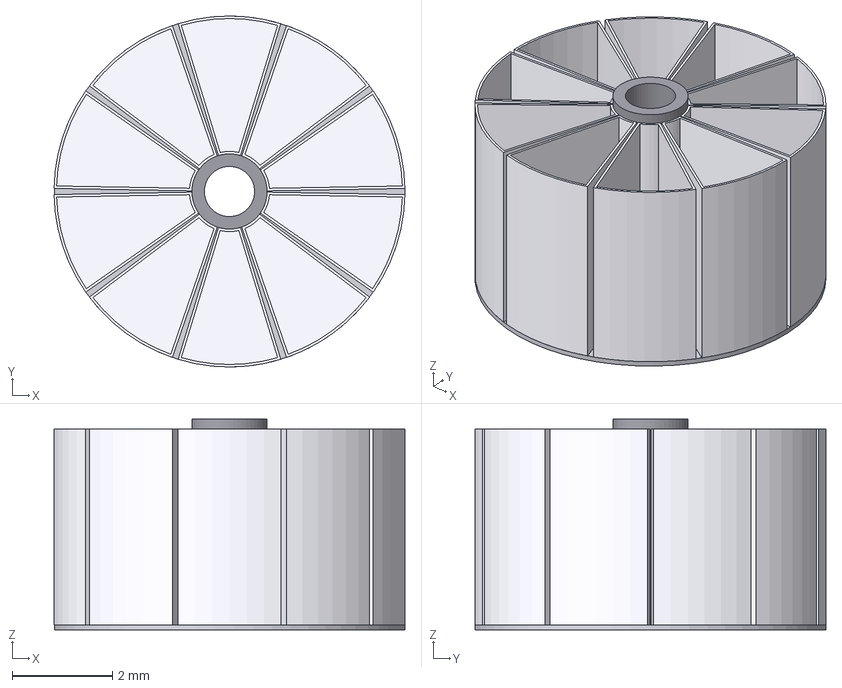
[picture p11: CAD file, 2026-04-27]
output/_test_carousel_full.step
7.00 x 7.00 x 4.20 mm
cartridge_00
cartridge_01
cartridge_02
cartridge_03
cartridge_04
cartridge_05
cartridge_06
cartridge_07
cartridge_08
cartridge_09
hub
base

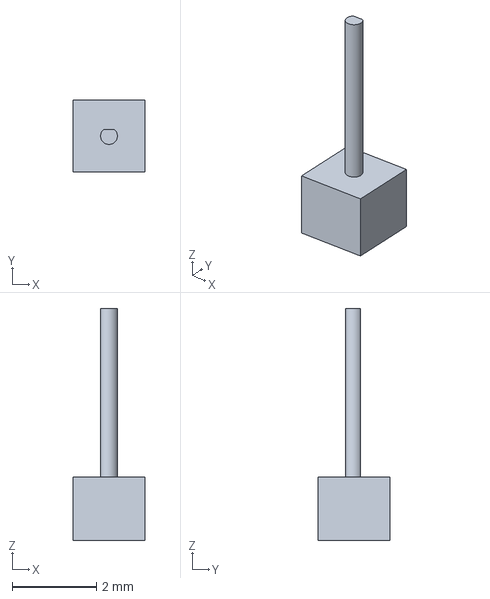
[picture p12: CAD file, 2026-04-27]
output/motor_assembly.step
1.70 x 1.70 x 5.50 mm

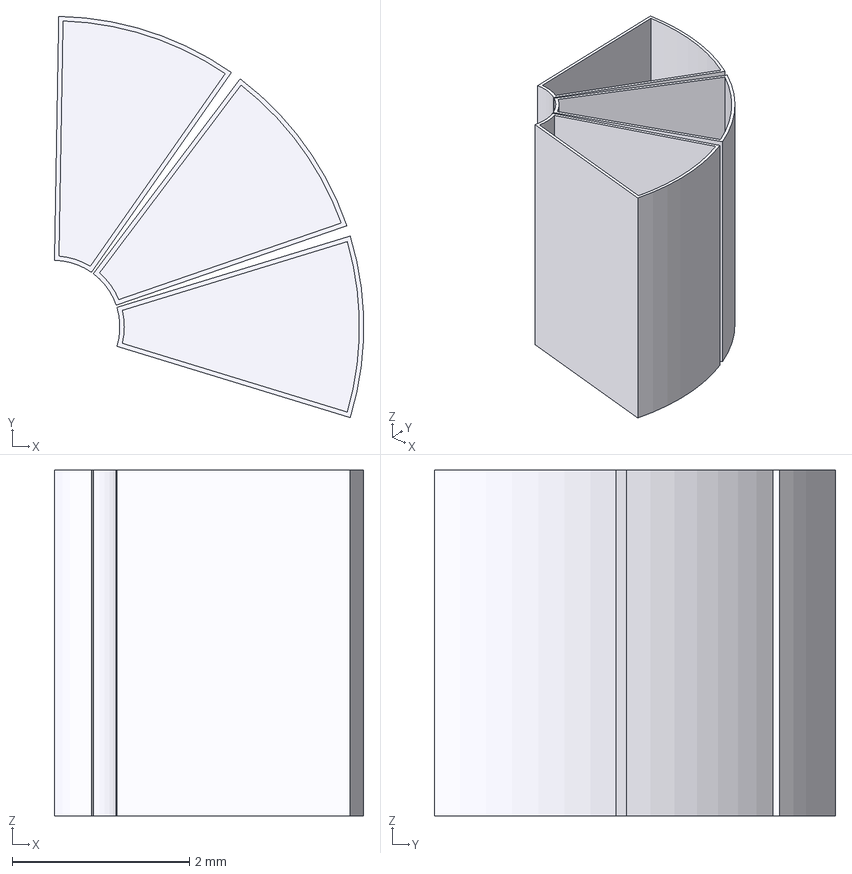
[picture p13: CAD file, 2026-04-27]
output/_test_assy.step
3.48 x 4.52 x 3.90 mm
cartridge_00
cartridge_01
cartridge_02

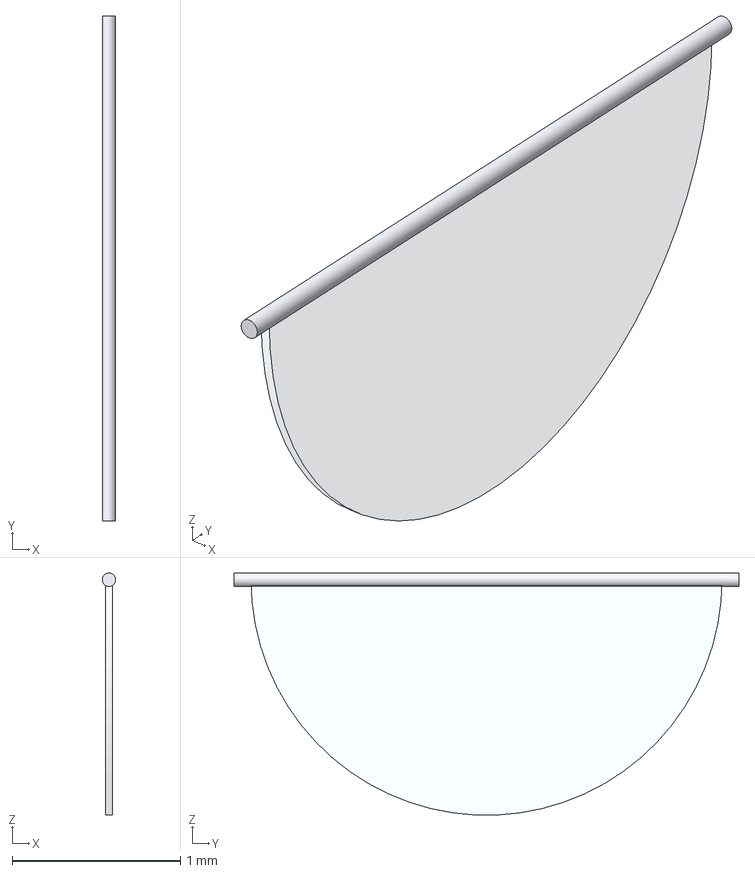
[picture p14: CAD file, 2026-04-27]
output/trapdoor_open_assembly.step
0.0799 x 3.00 x 1.44 mm
trapdoor_left_open
trapdoor_right_open
hinge_pin

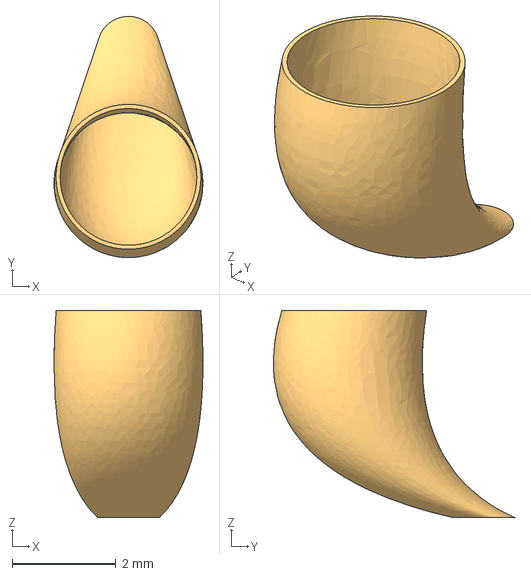
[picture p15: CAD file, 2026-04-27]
output/routing_chute_assembly.step
2.88 x 4.66 x 4.00 mm

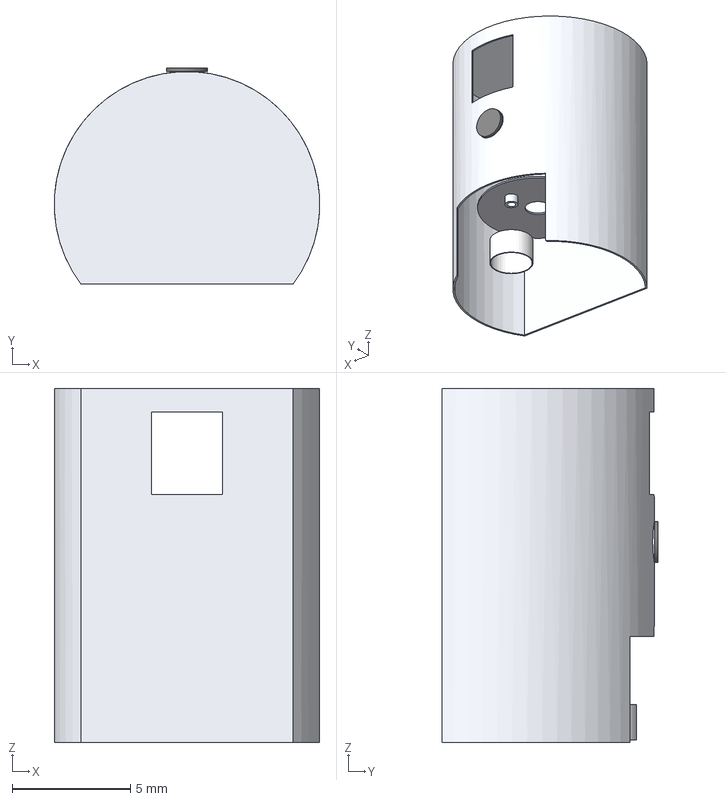
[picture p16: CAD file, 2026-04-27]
output/_test_hero_full.step
11.2 x 9.15 x 15.0 mm
enclosure
button
pill_cup
carousel_base_test

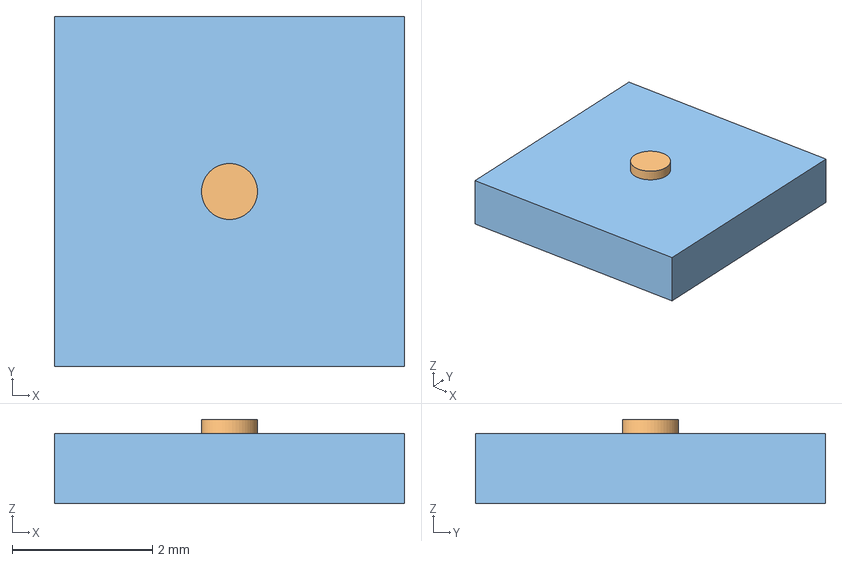
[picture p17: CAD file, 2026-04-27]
output/_test_nested_assy.step
5.00 x 5.00 x 1.20 mm
part_a
part_b

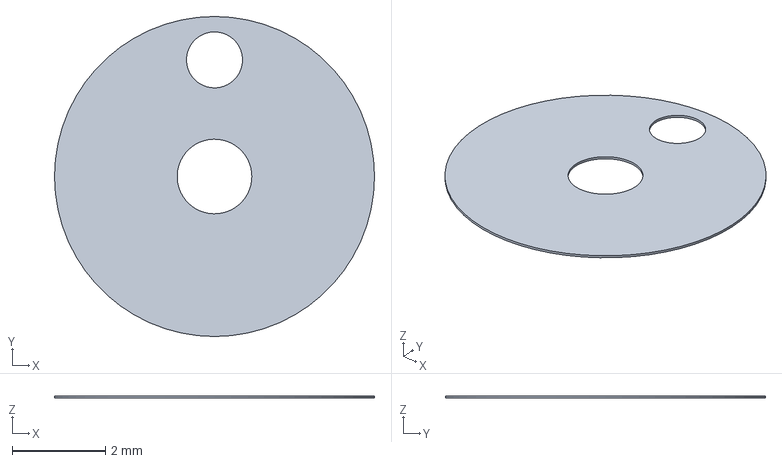
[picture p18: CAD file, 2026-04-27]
output/pill_guide_ring.step
6.86 x 6.86 x 0.05 mm

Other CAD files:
yesyes.step
output/dispense_gate.step
output/dispense_sweep_rail.step
output/pill_chute.step
des.f3d
output/_test_wp_export.step
output/agitator_wheel.step
output/button.step
output/camera.step
output/camera_arm.step
output/camera_mount.step
output/carousel_base.step
output/cartridge.step
output/center_hub.step
output/chamber_ceiling.step
output/chamber_shell.step
output/dispense_gate_servo_mount.step
output/dispense_release_gate.step
output/dispense_release_gate_servo_mount.step
output/dispense_sweep_containment_band.step
output/dispense_sweep_port_seal.step
output/dispense_sweep_pusher.step
output/dispense_sweep_pusher_deployed.step
output/dispense_sweep_servo_mount.step
output/display_panel.step
output/drop_cone.step
output/enclosure.step
output/enclosure_bottom.step
output/enclosure_middle.step
output/enclosure_top.step
output/guide_funnel.step
output/hatch_final.step
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

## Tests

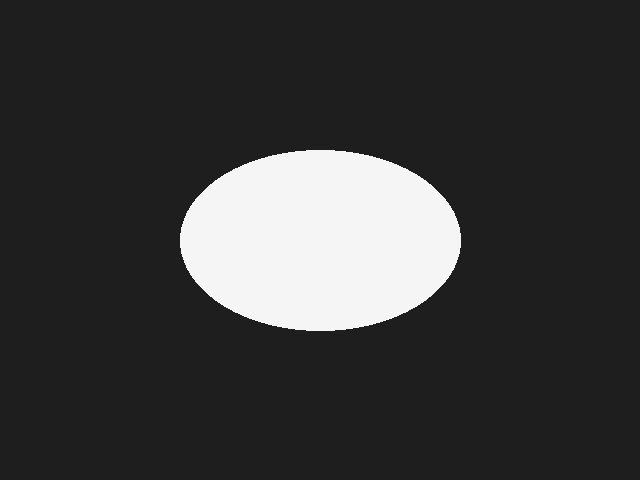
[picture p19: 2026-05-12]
detection/test_pill2.jpg

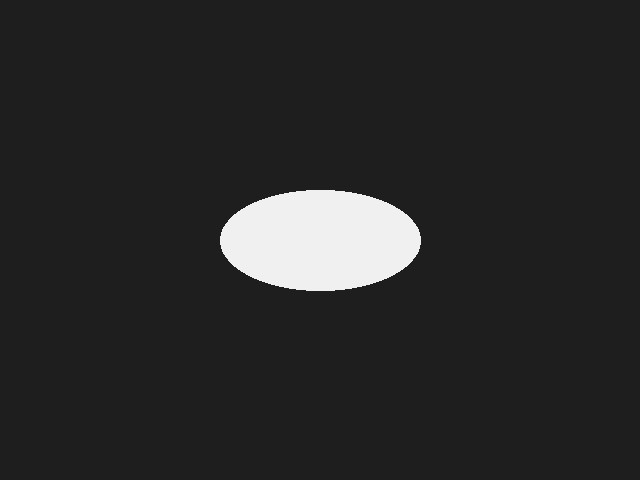
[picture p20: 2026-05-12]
detection/test_pill.jpg

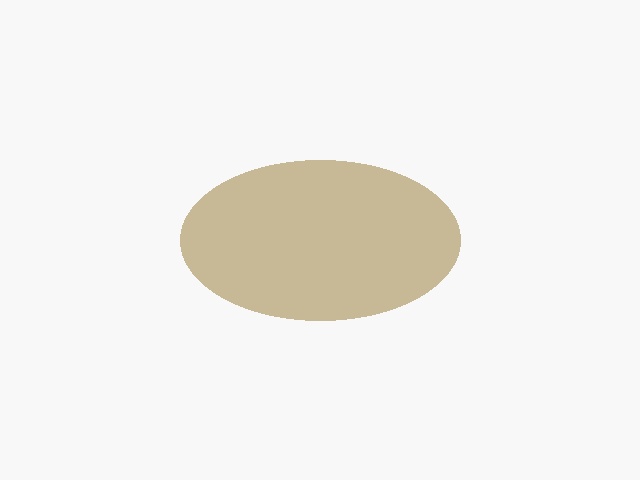
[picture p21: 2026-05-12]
detection/test_pill_correct.jpg

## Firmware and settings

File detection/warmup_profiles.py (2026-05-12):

"""
warmup_profiles.py
==================
Pre-lock pill detection profiles before a live demo.

Usage
-----
1. Start demo_server.py first:
       python demo_server.py

2. Send the demo prescription (or do it from the Flutter app).
   The server must know which medications exist before warm-up.

3. Run this script from the detection/ folder:
       python warmup_profiles.py --url http://localhost:5000 --pills-dir demo_pills

   Or to warm up a specific slot only:
       python warmup_profiles.py --slot 1

What it does
------------
For every medication slot it finds pills images in
  demo_pills/<slot_or_nhi_code>/  (jpg / png)

It sends the images one by one to POST /detect.
After 3 MATCHes the server auto-locks the profile.
The script shows a live progress table and stops early if a profile locks.

Synthetic pill generation (--generate flag)
------------------------------------------
If you don't have real photos yet, use --generate to create simple synthetic
beige-ellipse-on-white images (these work with the Otsu segmenter).
They won't be accurate for real detection but let you verify the pipeline
end-to-end before the photo session.

    python warmup_profiles.py --generate --slots 1,2,3
"""

import argparse
import io
import pathlib
import sys
import time

try:
    import requests
except ImportError:
    print("[warmup] requests not installed — pip install requests")
    sys.exit(1)


# ─────────────────────────────────────────────────────────────────────────────
# Helpers
# ─────────────────────────────────────────────────────────────────────────────

def _colour_for(result: str) -> str:
    """ANSI colour code for the terminal."""
    if result == "MATCH":    return "\033[92m"   # green
    if result == "UNSURE":   return "\033[93m"   # yellow
    if result == "NO_MATCH": return "\033[91m"   # red
    return "\033[0m"


def _reset() -> str:
    return "\033[0m"


def _detect(base_url: str, slot: int, image_path: pathlib.Path) -> dict:
    """POST /detect with a pill image and return the parsed JSON response."""
    with open(image_path, "rb") as f:
        data = f.read()
    resp = requests.post(
        f"{base_url}/detect",
        files={"image": ("pill.jpg", io.BytesIO(data), "image/jpeg")},
        data={"slot": str(slot)},
        timeout=30,
    )
    resp.raise_for_status()
    return resp.json()


def _get_status(base_url: str) -> dict:
    """GET /status to check which profiles are locked."""
    try:
        return requests.get(f"{base_url}/status", timeout=5).json()
    except Exception:
        return {}


def _make_synthetic_pill(width: int = 400, height: int = 400,
                          pill_colour=(210, 190, 150)) -> bytes:
    """
    Create a minimal JPEG: beige pill ellipse on a white background.
    Works with the Otsu segmenter (dark pill on bright background).
    Requires Pillow.
    """
    try:
        from PIL import Image as PILImage, ImageDraw
    except ImportError:
        print("[warmup] Pillow not installed — pip install Pillow")
        sys.exit(1)

    img = PILImage.new("RGB", (width, height), (240, 240, 240))
    draw = ImageDraw.Draw(img)
    cx, cy = width // 2, height // 2
    rx, ry = int(width * 0.30), int(height * 0.22)
    draw.ellipse([(cx - rx, cy - ry), (cx + rx, cy + ry)], fill=pill_colour)
    buf = io.BytesIO()
    img.save(buf, format="JPEG", quality=90)
    return buf.getvalue()


# ─────────────────────────────────────────────────────────────────────────────
# Main warm-up logic
# ─────────────────────────────────────────────────────────────────────────────

def warmup(base_url: str, pills_dir: pathlib.Path,
           target_slots: list[int] | None, min_matches: int,
           delay_s: float):
    """
    Iterate over pill images in pills_dir and call /detect until each
    slot's profile is locked (auto_registered == True) or we run out of images.
    """
    # Fetch initial server status to find active slots
    status = _get_status(base_url)
    slots_info = status.get("slots", {})

    if not slots_info:
        print("[warmup] WARNING: No slots returned from /status — "
              "send the prescription first.\n"
              "         Continuing anyway with whatever is in pills_dir …\n")

    # Resolve which slots to warm up
    if target_slots:
        slot_list = target_slots
    else:
        slot_list = sorted(int(s) for s in slots_info.keys()) if slots_info else []
        if not slot_list:
            # Fall back to sub-directories in pills_dir
            slot_list = sorted(
                int(p.name) for p in pills_dir.iterdir()
                if p.is_dir() and p.name.isdigit()
            )

    if not slot_list:
        print("[warmup] No slots to warm up.  "
              "Run --generate first or send a prescription from the app.")
        return

    print(f"[warmup] Warming up {len(slot_list)} slot(s): {slot_list}")
    print(f"         Server: {base_url}")
    print(f"         Min matches before stopping: {min_matches}\n")

    overall_ok = True
    for slot in slot_list:
        slot_dir = pills_dir / str(slot)
        if not slot_dir.exists():
            print(f"  Slot {slot}: no directory {slot_dir} — skipping")
            continue

        images = sorted(
            p for p in slot_dir.iterdir()
            if p.suffix.lower() in {".jpg", ".jpeg", ".png"}
        )
        if not images:
            print(f"  Slot {slot}: directory empty — skipping")
            continue

        med_name = slots_info.get(str(slot), {}).get("medicationName", f"Slot {slot}")
        print(f"  Slot {slot}  [{med_name}]  ({len(images)} image(s) available)")

        match_count   = 0
        locked        = False

        for i, img_path in enumerate(images):
            try:
                result = _detect(base_url, slot, img_path)
            except Exception as e:
                print(f"    [{i+1}/{len(images)}] ERROR: {e}")
                continue

            det     = result.get("result", "ERROR").upper()
            conf    = result.get("confidence", 0.0)
            acc_n   = result.get("accumulator_n", 0)
            auto_reg = result.get("auto_registered", False)
            col     = _colour_for(det)

            status_str = (
                f"    [{i+1:>2}/{len(images)}]  "
                f"{col}{det:<8}{_reset()}"
                f"  conf={conf:.3f}"
                f"  acc={acc_n}/{min_matches}"
            )
            if auto_reg:
                status_str += "  \033[92m✓ PROFILE LOCKED\033[0m"
                locked = True

            print(status_str)

            if det == "MATCH":
                match_count += 1

            if auto_reg or match_count >= min_matches:
                locked = True
                break

            if delay_s > 0:
                time.sleep(delay_s)

        if locked:
            print(f"  ✅  Slot {slot} profile LOCKED after {match_count} match(es)\n")
        else:
            print(f"  ⚠️   Slot {slot}: {match_count} match(es) — "
                  f"profile NOT locked (need {min_matches} images)\n")
            overall_ok = False

    if overall_ok:
        print("🎉  All profiles locked — dispenser is ready for the demo!")
    else:
        print("⚠️   Some profiles not locked.  "
              "Add more images under demo_pills/<slot>/ and re-run.")


# ─────────────────────────────────────────────────────────────────────────────
# Synthetic image generation
# ─────────────────────────────────────────────────────────────────────────────

def generate_synthetic(pills_dir: pathlib.Path, slots: list[int], count: int):
    """Write `count` synthetic pill JPEGs into demo_pills/<slot>/."""
    import random
    PILL_COLOURS = [
        (210, 190, 150),  # beige / generic
        (255, 235, 170),  # yellow
        (200, 170, 210),  # lavender
        (170, 205, 230),  # light blue
        (230, 175, 175),  # light pink
    ]
    print(f"[warmup] Generating {count} synthetic images for slots {slots}")
    for slot in slots:
        slot_dir = pills_dir / str(slot)
        slot_dir.mkdir(parents=True, exist_ok=True)
        colour = PILL_COLOURS[slot % len(PILL_COLOURS)]
        for i in range(1, count + 1):
            # Slightly vary colour per image for realism
            jitter = lambda v: max(0, min(255, v + random.randint(-10, 10)))
            c = tuple(jitter(x) for x in colour)
            data = _make_synthetic_pill(pill_colour=c)
            out  = slot_dir / f"synthetic_{i:03d}.jpg"
            out.write_bytes(data)
        print(f"  Slot {slot}: {count} images written to {slot_dir}")
    print()


# ─────────────────────────────────────────────────────────────────────────────
# Entry point
# ─────────────────────────────────────────────────────────────────────────────

def main():
    ap = argparse.ArgumentParser(
        description="Warm up pill detection profiles before a demo.",
        formatter_class=argparse.RawDescriptionHelpFormatter,
        epilog=__doc__,
    )
    ap.add_argument("--url",       default="http://localhost:5000",
                    help="Base URL of demo_server.py (default: http://localhost:5000)")
    ap.add_argument("--pills-dir", default=str(pathlib.Path(__file__).parent / "demo_pills"),
                    help="Directory containing per-slot pill images "
                         "(default: detection/demo_pills/)")
    ap.add_argument("--slot",      type=int, default=None,
                    help="Warm up a single slot only")
    ap.add_argument("--slots",     default=None,
                    help="Comma-separated list of slots to warm up, e.g. 1,2,3")
    ap.add_argument("--min-matches", type=int, default=3,
                    help="Stop per-slot after this many MATCHes (default: 3)")
    ap.add_argument("--delay",     type=float, default=0.3,
                    help="Seconds to wait between requests (default: 0.3)")
    ap.add_argument("--generate",  action="store_true",
                    help="Generate synthetic pill images (use before real photo session)")
    ap.add_argument("--generate-count", type=int, default=5,
                    help="Number of synthetic images per slot (default: 5)")
    args = ap.parse_args()

    pills_dir = pathlib.Path(args.pills_dir)

    # Resolve target slots
    target_slots: list[int] | None = None
    if args.slot:
        target_slots = [args.slot]
    elif args.slots:
        target_slots = [int(s.strip()) for s in args.slots.split(",") if s.strip()]

    if args.generate:
        if not target_slots:
            # Default to slots 1–5 for synthetic generation
            target_slots = list(range(1, 6))
        generate_synthetic(pills_dir, target_slots, args.generate_count)
        print("[warmup] Synthetic images created.  "
              "Re-run without --generate to start warm-up.\n")
        return

    warmup(
        base_url=args.url.rstrip("/"),
        pills_dir=pills_dir,
        target_slots=target_slots,
        min_matches=args.min_matches,
        delay_s=args.delay,
    )


if __name__ == "__main__":
    main()

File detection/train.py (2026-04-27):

"""
train.py — Fine-tune MobileNetV2 on ePillID (PyTorch) and export to ONNX.

Requires PyTorch with CUDA 12.8 for RTX 5080 (Blackwell):
    pip install torch torchvision --index-url https://download.pytorch.org/whl/cu128
    pip install onnx onnxruntime tqdm pandas scikit-learn

Then run:
    python train.py --epillid_dir ePillID_data
    python train.py --epillid_dir ePillID_data --epochs 30

ePillID dataset layout expected
---------------------------------
    ePillID_data/
        all_labels.csv                      ← label index for all images
        classification_data/
            fcn_mix_weight/dc_224/          ← consumer photos (main training set)
            fcn_mix_weight/dr_224/          ← reference photos
            segmented_nih_pills_224/        ← segmented images

Output
------
    models/pill_embedding.onnx   — copy this to the Pi

Two-phase training with ArcFace loss
-------------------------------------
    Phase 1: frozen backbone, train ArcFace head only          (~5 epochs)
    Phase 2: unfreeze last 2 MobileNetV2 feature blocks, fine-tune  (~N epochs)

    ArcFace adds an angular margin to the classification loss which forces
    embeddings of different pill classes to be angularly separated on the
    unit hypersphere. This directly improves cosine-similarity matching.
"""

import argparse
import time
from pathlib import Path
from PIL import Image

import numpy as np

# ── torch ─────────────────────────────────────────────────────────────────────

try:
    import torch
    import torch.nn as nn
    import torch.nn.functional as F
    from torch.utils.data import DataLoader, random_split
    from torchvision import datasets, transforms, models
except ImportError:
    raise SystemExit(
        "PyTorch is required.\n"
        "Install for RTX 5080 (CUDA 12.8):\n"
        "  pip install torch torchvision "
        "--index-url https://download.pytorch.org/whl/cu128"
    )

try:
    import onnx
except ImportError:
    raise SystemExit("Install onnx:  pip install onnx")

try:
    import pandas as pd
except ImportError:
    raise SystemExit("Install pandas:  pip install pandas")

try:
    from sklearn.model_selection import train_test_split
except ImportError:
    raise SystemExit("Install scikit-learn:  pip install scikit-learn")

try:
    from tqdm import tqdm
except ImportError:
    tqdm = None

# ── paths & constants ─────────────────────────────────────────────────────────

MODEL_DIR  = Path(__file__).parent / "models"
ONNX_PATH  = MODEL_DIR / "pill_embedding.onnx"

IMG_SIZE    = 224
EMBED_DIM   = 1280     # MobileNetV2 final conv output channels
NORM_MEAN   = [0.485, 0.456, 0.406]   # ImageNet stats (torchvision convention)
NORM_STD    = [0.229, 0.224, 0.225]


# ── ArcFace loss ──────────────────────────────────────────────────────────────

class ArcFaceLoss(nn.Module):
    """
    Additive Angular Margin Loss (ArcFace, Deng et al. 2019).

    Adds a fixed angular margin `m` to the angle between the embedding and
    the target class weight vector. This forces inter-class angular separation
    directly in the embedding space, making cosine-similarity matching reliable.

    s=64 and m=0.5 are standard values from the original paper.
    """

    def __init__(self, embed_dim: int, num_classes: int, s: float = 64.0, m: float = 0.5):
        super().__init__()
        self.s = s
        self.m = m
        self.W = nn.Parameter(torch.empty(embed_dim, num_classes))
        nn.init.xavier_uniform_(self.W)

    def forward(self, embeddings: torch.Tensor, labels: torch.Tensor) -> torch.Tensor:
        # Both embeddings and W columns are L2-normalised → dot = cosine
        W_norm  = F.normalize(self.W, p=2, dim=0)
        cosine  = torch.clamp(embeddings @ W_norm, -1.0 + 1e-7, 1.0 - 1e-7)  # [B, C]
        theta   = torch.acos(cosine)

        # Add margin only to the target class
        one_hot = torch.zeros_like(cosine).scatter_(1, labels.unsqueeze(1), 1.0)
        output  = torch.cos(theta + self.m * one_hot)

        return F.cross_entropy(output * self.s, labels)


# ── model ─────────────────────────────────────────────────────────────────────

class PillEmbedder(nn.Module):
    """
    MobileNetV2 backbone → 1280-dim L2-normalised embedding.
    ArcFaceLoss is used during training; at export only embed() is kept.
    """

    def __init__(self, num_classes: int):
        super().__init__()
        base = models.mobilenet_v2(weights=models.MobileNet_V2_Weights.IMAGENET1K_V1)
        self.backbone = base.features           # [B, 1280, 7, 7]
        self.pool     = nn.AdaptiveAvgPool2d(1) # [B, 1280, 1, 1]
        self.arcface  = ArcFaceLoss(EMBED_DIM, num_classes)

    def embed(self, x: torch.Tensor) -> torch.Tensor:
        """L2-normalised [B, 1280] embedding — used at export and inference."""
        feat = self.pool(self.backbone(x)).flatten(1)
        return F.normalize(feat, p=2, dim=1)

    def forward(self, x: torch.Tensor, labels: torch.Tensor) -> torch.Tensor:
        """Return ArcFace loss scalar for training."""
        return self.arcface(self.embed(x), labels)

    def freeze_backbone(self):
        for p in self.backbone.parameters():
            p.requires_grad = False

    def unfreeze_top_blocks(self, n_blocks: int = 2):
        total = len(self.backbone)   # 19 blocks in MobileNetV2
        for i, layer in enumerate(self.backbone):
            for p in layer.parameters():
                p.requires_grad = i >= (total - n_blocks)


# ── data ──────────────────────────────────────────────────────────────────────

class EpillIDDataset(torch.utils.data.Dataset):
    """
    Loads ePillID images using all_labels.csv.

    The CSV maps each image filename to a pill-type label string.
    We encode labels as integers and return (image_tensor, label_int).

    img_source controls which image set to use:
        'consumer'   — fcn_mix_weight/dc_224/  (varied conditions, best for training)
        'reference'  — fcn_mix_weight/dr_224/  (studio quality)
        'segmented'  — segmented_nih_pills_224/ (already cropped)
        'all'        — all three combined
    """

    def __init__(
        self,
        epillid_dir: Path,
        indices: list,
        df: "pd.DataFrame",
        label2idx: dict,
        transform,
        img_source: str = "consumer",
    ):
        self.root      = Path(epillid_dir) / "classification_data"
        self.df        = df.iloc[indices].reset_index(drop=True)
        self.label2idx = label2idx
        self.transform = transform

    def __len__(self):
        return len(self.df)

    def __getitem__(self, idx):
        row       = self.df.iloc[idx]
        img_path  = self.root / row["image_path"]
        label_idx = self.label2idx[row["label"]]
        img = Image.open(img_path).convert("RGB")
        return self.transform(img), label_idx
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

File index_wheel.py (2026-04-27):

# Hero Pill Dispenser -- Carousel Index Wheel & Optical Sensor Mount
# Phase 16: Position feedback for accurate carousel indexing.
#
# The NEMA 17 stepper gives relative step counts but has no home reference.
# An optical interrupter (fork-type, e.g. TCST2103) on a slotted index disk
# attached to a rear shaft extension gives ONE absolute home pulse per revolution.
# The firmware homes at startup, then counts 360/N_SLOTS = 36 deg/step-group to
# reach any of the 10 cartridge positions.
#
# Coordinate system (matches carousel.py):
#   X: left(-) / right(+), centre = 0
#   Y: back(0) / front(9)
#   Z: bottom(0) / top(15)   -- all in inches
#
# Parts produced:
#   rear_shaft.step       -- D-shaft extension below motor body (rotates)
#   index_disk.step       -- slotted index disk on rear shaft  (rotates)
#   sensor_mount.step     -- L-bracket + optical sensor body   (stationary)
#   index_wheel_assembly.step
#
# Run with: C:\Users\jaime\AppData\Local\Python\pythoncore-3.12-64\python.exe index_wheel.py
# Run BEFORE carousel.py (outputs are imported by carousel.py guard block).

import cadquery as cq
import math
import pathlib

OUTPUT = pathlib.Path("output")
OUTPUT.mkdir(exist_ok=True)

# ---------------------------------------------------------------------------
# Constants -- copied from carousel.py (no circular import)
# ---------------------------------------------------------------------------
CAROUSEL_X      = 0.0
CAROUSEL_Y      = 4.5

# Motor / mount geometry (from carousel.py verification):
#   motor_mount: Z=[3.300, 3.400]   motor body: Z=[3.400, 4.900]
MOTOR_Z_BOT     = 3.40    # motor body bottom = motor mount plate top
MOTOR_MOUNT_BOT = 3.30    # motor mount plate bottom face

# D-shaft geometry (must match carousel.py exactly)
SHAFT_R          = 0.20   # 5.08 mm -- real NEMA 17 shaft diameter
SHAFT_FLAT_DEPTH = 0.05   # flat cut depth on +Y side

# ---------------------------------------------------------------------------
# Rear shaft extension
# ---------------------------------------------------------------------------
# The main D-shaft goes UP into the carousel.  This extension goes DOWN,
# through the motor mount plate hole, below the motor face.
# A clearance hole is assumed in the motor mount plate (not modelled here --
# motor_mount.py would need updating; for now the extension is shown floating).
REAR_SHAFT_LEN   = 0.50   # 12.7 mm extension below motor body bottom
REAR_SHAFT_Z_TOP = MOTOR_Z_BOT                      # 3.40"
REAR_SHAFT_Z_BOT = MOTOR_Z_BOT - REAR_SHAFT_LEN     # 2.90"

# ---------------------------------------------------------------------------
# Index disk
# ---------------------------------------------------------------------------
# Sits on the rear shaft between motor body bottom and motor mount plate,
# just below the motor mount plate underside (Z=3.30).
INDEX_DISK_R     = 0.60   # 15.2 mm outer radius -- visible to sensor fork
INDEX_DISK_T     = 0.05   # 1.27 mm thickness -- fits inside standard 3 mm fork gap
INDEX_DISK_Z_CTR = 3.15   # disk centre Z -- 0.15" below motor mount bottom (3.30)

# D-bore: shaft fit (clearance = 0.01" radially + flat clearance)
INDEX_BORE_R     = SHAFT_R + 0.01                   # 0.21" bore radius
INDEX_BORE_FLAT  = SHAFT_FLAT_DEPTH + 0.01          # 0.06" flat clearance

# Index notch -- rectangular radial slot at angle 0 deg (+X direction)
# The notch interrupts the sensor beam once per revolution = home reference.
INDEX_NOTCH_DEPTH = 0.20   # radial depth from outer rim inward (to R=0.40")
INDEX_NOTCH_W     = 0.14   # notch arc chord width at outer rim (~13 deg)
                            # wide enough for reliable detection, narrow enough
                            # that the motor can stop accurately inside the window

# ---------------------------------------------------------------------------
# Optical sensor + bracket
# ---------------------------------------------------------------------------
# Sensor: TCST2103 fork-type optical interrupter (or equivalent)
#   Body: 11.9 mm x 10.8 mm x 4.0 mm  =>  0.47" x 0.43" x 0.16"
#   Fork gap: 3.0 mm (0.118") -- index disk 1.27 mm fits with 1.73 mm clearance
#   Mounting: two M2 screws through sensor feet into bracket
SENSOR_BODY_X    = 0.16   # sensor body depth (X, along radial direction)
SENSOR_BODY_Y    = 0.47   # sensor body width (Y, tangential)
SENSOR_BODY_Z    = 0.43   # sensor body height (Z)
SENSOR_FORK_GAP  = 0.12   # fork gap (> INDEX_DISK_T = 0.05" -- OK)

# Bracket geometry
BRACKET_T        = 0.06   # wall thickness of L-bracket
# Sensor fork sits at disk outer rim: X = CAROUSEL_X + INDEX_DISK_R = 0.60"
# Sensor positioned at +X side (home notch at angle 0 deg from +X)
SENSOR_X_CTR     = CAROUSEL_X + INDEX_DISK_R        # 0.60" from carousel axis X
SENSOR_Y_CTR     = CAROUSEL_Y                       # 4.50" -- aligned with shaft Y
SENSOR_Z_CTR     = INDEX_DISK_Z_CTR                 # 3.15" -- same Z as disk

# Bracket vertical arm: hangs from motor mount plate bottom (Z=MOTOR_MOUNT_BOT=3.30)
# down to sensor Z - half sensor height
BRKT_ARM_Z_TOP   = MOTOR_MOUNT_BOT                  # 3.30"
BRKT_ARM_Z_BOT   = SENSOR_Z_CTR - SENSOR_BODY_Z / 2 - 0.02  # ~2.915"
BRKT_ARM_H       = BRKT_ARM_Z_TOP - BRKT_ARM_Z_BOT  # ~0.385"

# Bracket horizontal arm: from near shaft to sensor X position
# Arm starts at X = CAROUSEL_X (shaft centreline) + small offset to clear shaft
BRKT_H_ARM_X_START = CAROUSEL_X + SHAFT_R + 0.05    # 0.25" from shaft centre
BRKT_H_ARM_X_END   = SENSOR_X_CTR                   # 0.60"
BRKT_H_ARM_LEN     = BRKT_H_ARM_X_END - BRKT_H_ARM_X_START  # 0.35"

# ---------------------------------------------------------------------------
# Helper
# ---------------------------------------------------------------------------
def save_step(wp, fname):
    wp.export(str(OUTPUT / fname))
    print(f"  Wrote output/{fname}")

def make_d_bore_cut(r_bore, flat_depth, height):
    """Return a cutter for a D-shaped bore centred at (0,0), extruding +Z by height+0.02."""
    bore_cyl = cq.Workplane("XY").circle(r_bore).extrude(height + 0.02).translate((0, 0, -0.01))
    _pad      = 0.20
    _box_W    = r_bore * 2 + _pad
    _box_dep  = flat_depth + _pad
    _Y_flat   = r_bore - flat_depth
    _box_cY   = _Y_flat + _box_dep / 2
    flat_box  = (
        cq.Workplane("XY")
        .center(0, _box_cY)
        .rect(_box_W, _box_dep)
        .extrude(height + 0.02)
        .translate((0, 0, -0.01))
    )
    return bore_cyl.union(flat_box)
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
